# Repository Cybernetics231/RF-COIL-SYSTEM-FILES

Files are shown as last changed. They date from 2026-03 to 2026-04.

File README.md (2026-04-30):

# DB25 Control Software (Arduino + Avalonia UI)

This repository contains the full DB25 control software used to interface with an Arduino-based DB25 I/O system. It includes both the Avalonia-based graphical interface and the Arduino firmware that the GUI communicates with. The intent of this project is to allow anyone, even with no prior experience, to recreate the setup, understand how it works, and modify it if needed.

The graphical interface is built using Avalonia.NET to ensure compatibility with both Linux and Windows. The `.axaml` file defines the visual layout of the interface, while the `.axaml.cs` file contains the backend logic responsible for serial communication, pin updates, gain control, and pulse control. These two files together form the complete GUI.

For users who simply want to run the software, a ready-to-launch build is included in the `DB25 Mk3 Linux.rar` file. Extracting this archive provides the compiled `.exe` along with all required runtime files. This executable contains only the GUI portion of the project. The Arduino firmware must be uploaded separately and can be found in the `sketch_mar11a/sketch_mar11a.ino` directory.

If you intend to build on top of this software or compile the GUI yourself, the process is straightforward. Begin by installing the Avalonia UI .NET package and creating a new Avalonia project in Visual Studio. Once the project is created, replace the generated `.axaml` and `.axaml.cs` files with the versions from this repository titled `MainWindow.axaml` and `MainWindow.axaml.cs` by copying their contents directly into the corresponding files in your new project. After that, open a PowerShell terminal inside the project directory and compile the application using a publish command such as:

"dotnet publish -c Release -r win-x64 --self-contained true -o "$env:USERPROFILE\Downloads"" (Without end start and end quotations)

This will generate a standalone executable that can be run on Windows without requiring any additional installations.

The Arduino firmware used by the GUI is included in this repository and is located at `sketch_mar11a/sketch_mar11a.ino`. Upload this file to your Arduino using the Arduino IDE. Once the firmware is running, the GUI will automatically communicate with the board over serial, allowing you to read DB25 input pins, write output pins, adjust gain values, and control pulse output.

In addition to the software and firmware, this repository contains a folder titled **TEAM Files**, which includes the complete set of documents, calculations, and design artifacts produced during the capstone project. This folder is organized into several subdirectories. The `01-admin` folder contains all capstone-related documentation, including the final report and every presentation delivered to the sponsor, academic advisor, and other stakeholders. This is the best resource for understanding the full development process, design decisions, and project evolution.

The `02-RF amplifier` folder contains handwritten calculations, verification work, and a Python script used to compute the required input signal for the RF system. This is especially useful if the coil parameters change, as the script can be used to quickly recompute the necessary input waveform. The `03-TR switch` folder contains CAD files related to the transmit/receive switching hardware. The `05-Coil` folder includes coil parameters and VNA screenshots used during tuning and validation. Finally, the `Capstone fair` folder contains the poster and block diagram used during the public capstone showcase.

Some redundant files exist in the repository due to earlier development stages, but all essential components are present and functional. The goal is to provide a complete and transparent reference for anyone who wants to understand, use, or extend what was accomplished by the Capstone team of 2026 for the ULF RF System.

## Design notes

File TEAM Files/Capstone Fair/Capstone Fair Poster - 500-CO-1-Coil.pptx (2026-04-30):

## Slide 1

A Radio Frequency Coil for Ultra Low-Field MRI

Author(s): Jennifer Bee, Sonny Bruni, Yuri Lemermeyer, Kenshin Pacle, Spencer Tourigny, Ian Washington
Department of Electrical and Software Engineering at Schulich School of Engineering

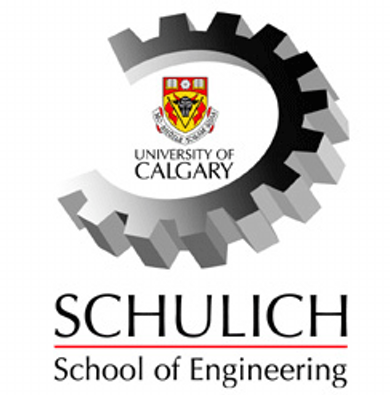
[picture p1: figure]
A new champion joins the 30 by 30 cause | Engineers Canada
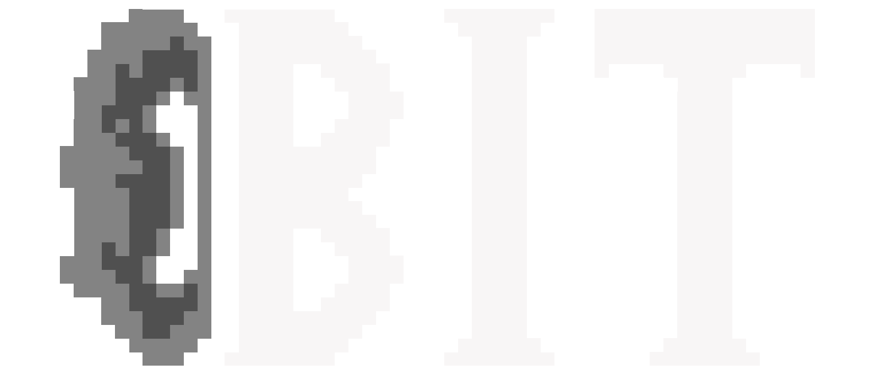
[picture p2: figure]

Introduction and Background

- Magnetic Resonance Imaging (MRI) is a key medical diagnostic tool. However, it is expensive because of the large magnetic fields it uses.

- Ultra-Low Field (ULF) MRI uses much lower magnetic fields, giving it the potential to make healthcare more affordable and accessible.
- Our project is the RF coil system of a ULF MRI. This system both excites the specimen and receives the signal it produces, which is processed into the image.

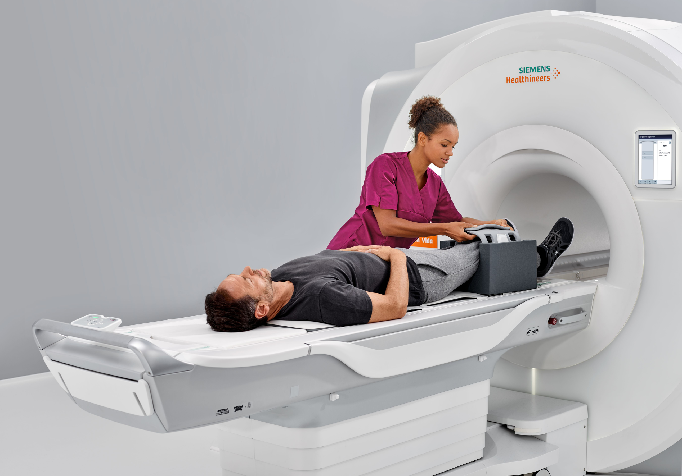
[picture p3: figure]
MRI Group – MRI Imaging Technology Includes Open MRI Machines

Tuning Circuit

- We manipulate the resonant frequency of the coil by adding capacitance in parallel.
- Series capacitance is added to maximize power transfer through impedance matching.

Simulations

- We simulated our coil’s resonant frequency and inductance to validate experimental results.

- Simulated resonant frequency: 4.221MHz
- Simulated inductance: 50μH

Results

- Achieved 2.18MHz tune with -43dB match
- Quality Factor (loaded with specimen): 175

Tuning of 2.18MHz ensures sample nuclei are properly excited.
Matched coil below -25dB indicates high efficiency power transfer.

Q Factor > 88 meets our goal for frequency selectivity because of its impact on signal to noise ratio.

- Experimental resonant frequency: 4.148MHz
- Experimental inductance: 54μH

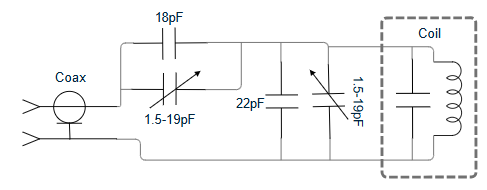
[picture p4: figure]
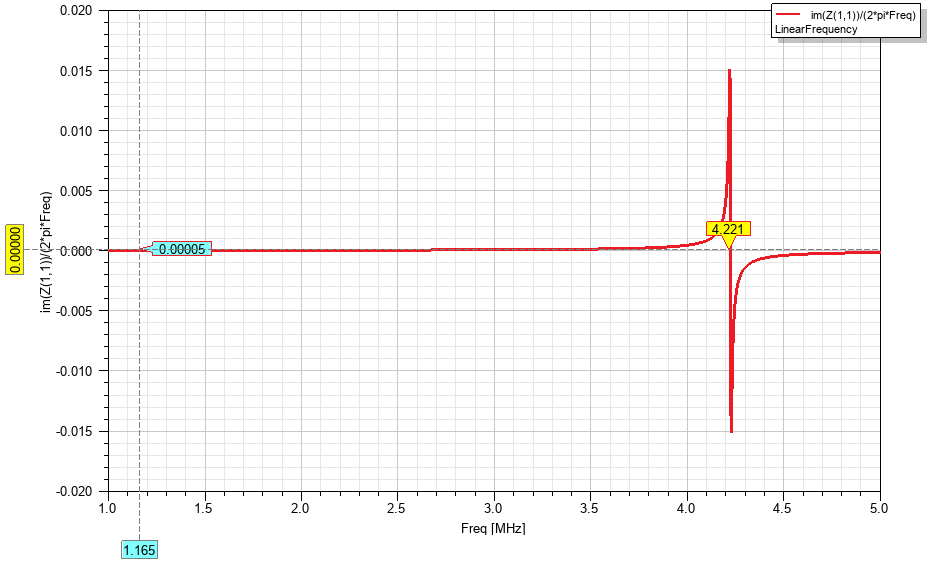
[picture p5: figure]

Radio Frequency Excitation

- RF Excitation is a phenomena where short bursts of radio waves at a specific frequency tilt the atoms of a magnetized sample away from a resting position.

- As the atoms decay back to their resting position, a distinct signal is produced which is used for imaging.

RF Amplifier

- The amplifier boosts a small signal, so the coil creates a strong enough field to tilt to the atoms. It is controlled via a 25-pin interface, by an Arduino and in-house GUI.

Transmit and Receive Switch

- The TR switch isolates the transmit and receive paths and quickly switches between them.

- Several factors including power handling and attenuation were considered for the selected design.

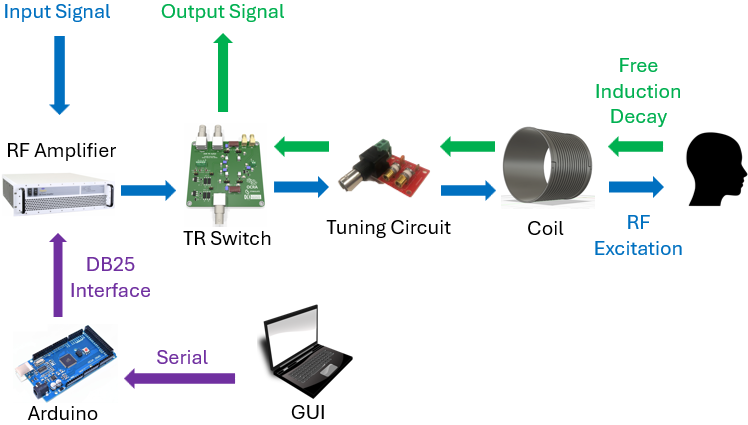
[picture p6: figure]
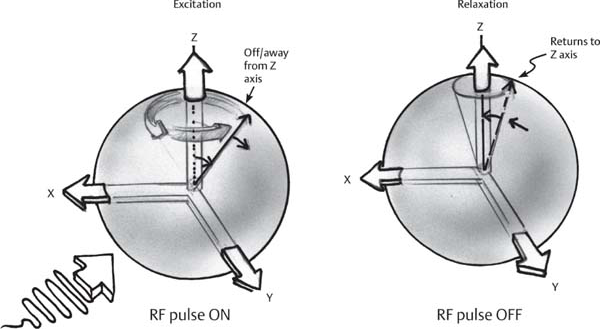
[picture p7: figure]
Essentials of MRI Physics and Pulse Sequences | Radiology Key

Coil Design

- Outer and inner diameters are 28.4cm and 26.4cm
- The coil has 15 turns, which sets the inductance

Geometric constraints permit measurement of adult heads and accommodate our sponsor’s existing ULF system.

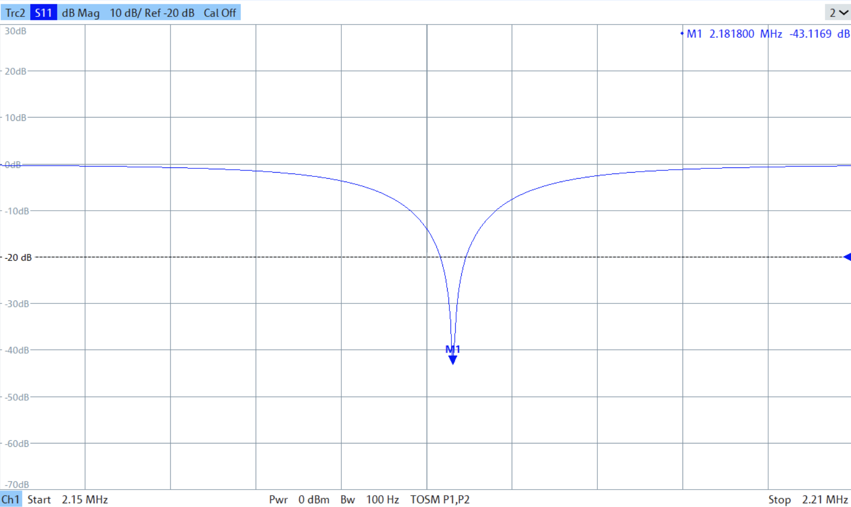
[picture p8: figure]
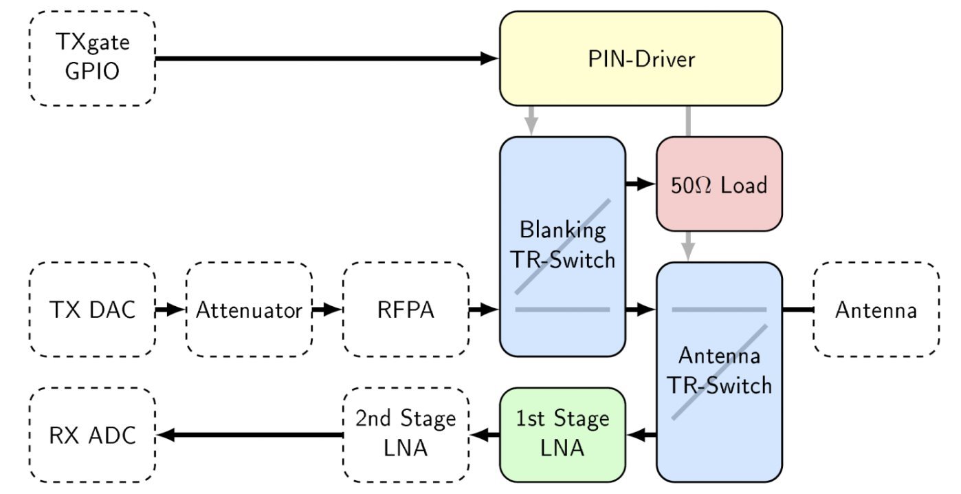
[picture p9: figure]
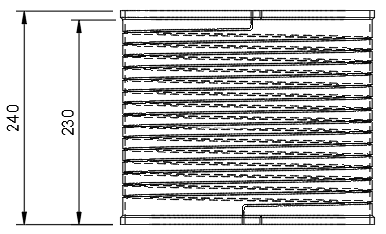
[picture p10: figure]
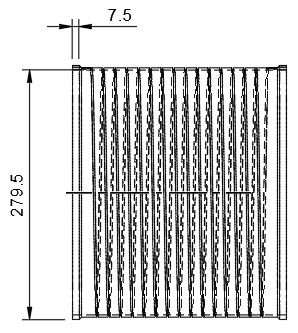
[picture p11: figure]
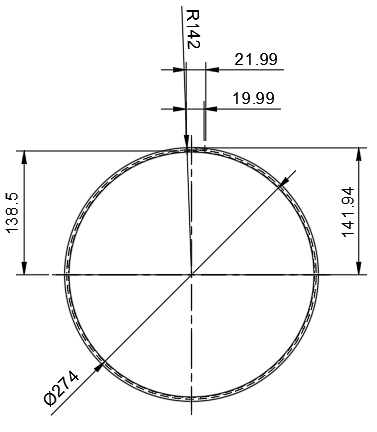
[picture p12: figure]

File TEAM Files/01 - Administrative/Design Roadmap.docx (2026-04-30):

A Radiofrequency Coil for Ultra Low-Field MRI

Design Roadmap

500-CO-1-Coil

Project Manager

Spencer Tourigny, 30117572, spencer.tourigny@ucalgary.ca

Team

Sonny Bruni, 30149849

Ian Washington, 30116633

Jennifer Bee, 30094595

Yuri Lemermeyer, 30143884

Kenshin Pacle, 30116862

Support Technician

Mateo Alzate

Academic Advisor

Dr. Chathura Kumaragamage

Company Sponsor

Brain Image Team (BIT) Lab

Dr. Ethan MacDonald, ethan.macdonald@ucalgary.ca

Table of Contents

# 1 Glossary

Acronyms | Definitions
RF | Radio Frequency
MRI | Magnetic Resonance Imaging
TR | Transmit-Receive
FID | Free Induction Decay
PCB | Printed Circuit Board
ULF | Ultra Low Frequency

Table 1: Definition of Acronyms Used Throughout the Document

Terms | Definitions
Larmor Frequency | Frequency of a charged particle’s magnetic moment in an external magnetic field
Free Induction Decay | Time-domain signal that appears immediately after a radio frequency pulse excites a sample’s nuclear spins.
Specimen | The object being imaged by the MRI

Table 2: Definition of Terms Used Throughout the Document

# 2 Short Bios

## 2.1 Spencer Tourigny

Final year Electrical Engineering and Commerce dual degree student. Industry experience in facilities engineering, electrical design, and maintenance engineering. Also completed a summer of undergraduate research in the University of Calgary control systems lab.

## 2.2 Jennifer Bee

Final year Electrical Engineering student with internship experience at the department of National Defence. Experience within RF detection systems and researched diode detection through RF excitation.

## 2.3 Ian Washington

Final year Electrical Engineering student with industry experience in fiber optic technology, data processing algorithms, and pipeline operations. Completed a digital engineering-focused fellowship opportunity at the University of Calgary.

## 2.4 Sonny Bruni

Final year Electrical Engineering student with industry experience in data analytics, manufacturing and engineering optimization.

## 2.5 Kenshin Pacle

Final year Electrical Engineering student with an industry background in software development and electrical systems. Interests in bridging software to hardware, and artificial intelligence.

## 2.6 Yuri Lemermeyer

Final year Electrical Engineering student with industry experience in power systems and data analytics.

# 3 Project Motivation and Objectives

## 3.1 Motivation

MRI is a diagnostic tool used to visualize the body’s internal structures. It is critical in diagnosing several ailments, including brain injuries, tumours, aneurysms, spinal cord conditions, and strokes (Mayo Clinic, 2023). However, conventional MRI machines rely on strong magnetic fields, which require expensive parts and complex fabrication. These factors make MRI technology inaccessible in many parts of the world, especially rural areas and third-world countries.

ULF MRI addresses this problem by offering an alternative approach. It uses weak magnetic fields, effectively reducing the size, cost and complexity of MRI systems. However, using a weak magnetic field creates new challenges, such as weak signals and blurry images, requiring thoughtful design to create a feasible solution. The RF coil, the part of a MRI which transmits and receives signals from the object being scanned, is especially impacted by the use of ULF, as the signal-to-noise ratio radically decreases in ULF applications.

## 3.2 Objectives

The main goal of this project is to design, build and test an RF coil optimized for ULF MRI applications. By completing this project, the team aims to contribute to the development of more affordable and accessible MRI technology. Ultimately, this project supports efforts to make healthcare more equitable and affordable through innovative engineering.

# 4 Project Scope and Deliverables

## 4.1 Project Scope

The scope of this project entails the design, fabrication, implementation, and validation of an RF coil to be used in the application of an ultra-low field MRI. The coil will serve as the primary driver for nuclear spin excitation in the specimen, as well as the reception of the free induction decay signal after radio signal pulsation at the Larmor frequency.

The final system shall include:

- An RF Coil.
- A tuning circuit that optimizes power transfer to the coil.
- A TR switch to control transmitting and receiving modes of the coil.
- An RF power amplifier to drive the Larmor frequency signal to the coil.

The coil, as well as the supplemental components shall be designed given the constant that the ultra-low field MRI produces a constant magnetic field of 50mT.

Functionality wise, the RF coil shall be capable of bimodal operation, utilizing both transmit and receive modes governed by the TR switch. In transmit mode, the coil shall be able to deliver an RF signal at the Larmor frequency corresponding to the defined magnetic field strength, driven by an RF amplifier, to induce excitation in the specimen. In receiving mode, the coil shall detect the FID signal resulting from free induction decay.

Constructing an image from the FID signal, main magnetic field generation for magnetizing the specimen, or any other functionalities that a completely functional ultra-low field MRI has is out of scope for this project.

## 4.2 Project Deliverables

Must-Have:

  - Functional RF Coil able to transmit and receive.
  - RF amplifier either designed or bought.
  - T/R Switch either designed or bought.
  - Tuning Circuit, tuning the coil for max power designed on a PCB.
  - Bill of materials.
  - Simulation results.
  - CAD Models for enclosures and Drawings.
  - 3D Printed enclosures for relevant components.
  - Documentation regarding design, as well as any supporting documentation or calculations.
  - Validation results, as well as metrics for performance of the system.

Should-Have:

- Modular PCB layout for Tuning circuit
- Solenoid coil design as opposed to traditional coil design.
- External circuit protection consisting of relays and fuses spread out through the components of the design.

Nice-to-Have

- Coil segmentation, Bandpass filters, decoupling capacitors, or any other noise mitigation implementations.
- Heat protection.
- Aesthetically pleasing enclosure.

# 5 Preliminary Design of the Proposed Solution

The RF coil system can be represented by the block diagram in Figure 1.

Figure 1: System Block Diagram

The basic function of the RF coil system is to take an input signal (supplied to the system, outside the scope of the project) and use it to generate a visualization of the specimen in the MRI. This visualization signal is outputted from the RF coil system to be processed (image processing is outside the scope of this project).

The RF coil performs this functionality by oscillating between two modes of operation: transmitting and receiving.

In transmission mode the system behaves as shown in Figure 2. The input signal is amplified by the RF amplifier and passes through the TR switch. The coil acts as a transmitting antenna, transmitting the signal into the specimen. This causes the spins of the hydrogen atoms in the specimen to align, creating a net magnetic moment in the specimen (Gould & Edmonds, 2023).

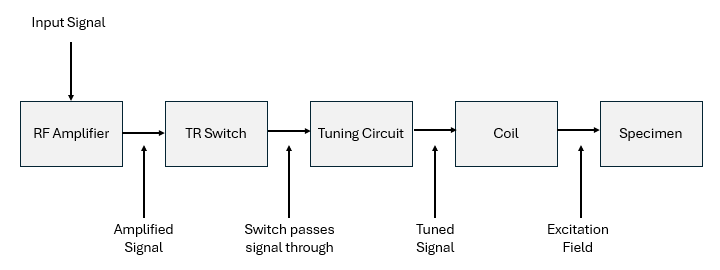
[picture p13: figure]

Figure 2: Transmission Mode Diagram

The system than switches to receiving mode. This causes the coil to stop acting as a transmitting antenna, ceasing the excitation of the specimen. However, the net magnetic moment in the specimen takes a while to decay (Gould & Edmonds, 2023). This gives us the chance to use the coil as a receiving antenna, picking up the FID signal generated by the specimen. This signal is passed through the RF coil system as shown in Figure 3, eventually being outputted and used to produce the visualization of the specimen.

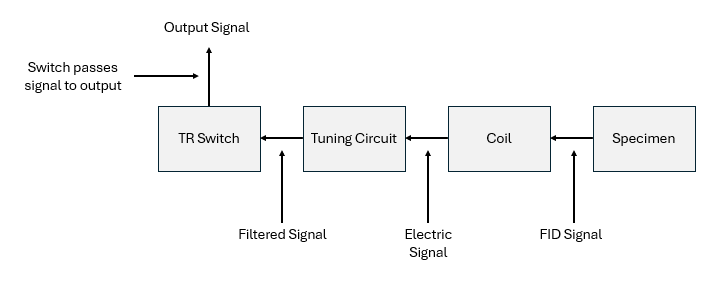
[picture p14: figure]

Figure 3: Receiving Mode Diagram

These block diagrams show the project design can be broken into 4 main components: the coil, the TR switch, the RF amplifier, and the tuning circuit.

## 5.1 Coil

The coil is made up of an antenna and housing. The size of the coil and coil housing is very important because it must fit the specimen inside it, while being able to fit inside the larger permanent and gradient magnets itself. Sizing requirements are given in the technical requirements. To reliably meet these sizing requirements, and simplify construction of the housing, the housing will be 3D printed.

The antenna itself can have several design alternatives, though most involve wrapping magnet wire around the housing in some configuration. These configurations will be discussed in the alternative solutions section below. The use of magnet wire is important for the antenna to effectively transmit a signal to the specimen.

## 5.2 TR Switch

There are several TR switch designs which have been used in MRI systems over the years, including both active and passive switching options. To avoid repetition, I will save the discussion of these alternative switches and our planned path forward for the alternative solutions section of this report.

## 5.3 RF Amplifier

Our sponsor purchased an RF amplifier prior to the beginning of our project with them. This purchased RF amplifier is a Tomco brand 3MHz RF amplifier. Our design should be compatible with this amplifier.

## 5.4 Tuning Circuit

Our tuning circuit will be based off the design done by Tom O’ Reilly and Lukas Winter, who developed a tuning circuit for a similar ULF MRI application (O’ Reilly & Winter, 2025). A schematic of O’Reilly and Winter’s tuning circuit design is given in Figure 4.

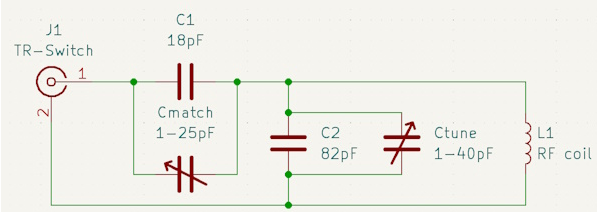
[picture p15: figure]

Figure 4: O’Reilly and Winter's Tuning Circuit Schematic

However, our design will have to make a few changes to this design. First, the variable capacitors they used are not readily available in North America. Instead, we will use alternative variable capacitors in our designs. These capacitors have different capacitance ranges than the ones used by O’ Reilly and Winter. To get an equivalent circuit with different capacitance ranges, we will need different capacitance and inductance values for static components. To test that our redesigned circuit still functions correctly, we will prototype it on a breadboard, to test its functionality. After we have confirmed the functionality of our tuning circuit, we will print a tuning circuit PCB, to eliminate any stray breadboard capacitances from the final design.

# 6 Alternative Solutions and Methodologies

## 6.1 General Approach to Design Alternatives

Since low-field MRI devices are a new technology with limited pre-set industry standards, and limited literature and research papers available, there have been cases where the team and/or sponsor have chosen to use off-the-shelf, pre-built components for initial testing and validation. This way, troubleshooting is much more straightforward and there is a working example with which to base further designs off.

The downsides of using this approach are that in some cases using pre-built components is more expensive than designing a solution ourselves, and that pre-built components are more difficult/impossible to modify if needed.

## 6.2 Simulation Software Alternatives

Simulation software was chosen based on familiarity, technical capabilities, and cost. The three main options considered were Python, MATLAB and Ansys Electronics Desktop. MATLAB was familiar to the team but not specifically for electromagnetic and radio-frequency modelling and is limited to relatively rudimentary geometric modelling. For our use case, Python has mostly the same benefits and drawbacks as MATLAB. Experience with Ansys was limited to a few labs in previous classes, however it has superior ability to model geometry, and simulate radio frequency responses. MATLAB and Ansys provide university students access to a free version. In Ansys Electronics Desktop Student the user is limited to 10,000 meshes which has limited, but not detrimentally so our simulations. We chose Ansys as a more specialized and powerful tool for MRI modelling.

## 6.3 RF Coil Design Alternatives

For the design of the main RF coil, we considered three configurations: birdcage, solenoid (helix), and surface coils. Factors considered included the specialization of the coil, such as depth of imaging and quality of signal to noise ratio. We also took into account coil design, simulation and manufacturing complexity. Lastly, we considered availability of open-source information about design and performance as a favourable source of guidance. Surface coils would have been a strong choice in a different context of imaging. If our focus was limited to shallow images (such as wrists, elbows, knees, etc.) we would have considered these coils further. However, these designs are very complex and the amount of open-source information available regarding these coils is not plentiful. Between the remaining two choices of coils, birdcage have better field homogeneity. While this is an important parameter, it was outweighed in favour of the solenoid design’s superior signal to noise ratio, significantly simpler design and plentiful access to open-source resources. We heavily referenced open-source resources provided by Lukas Winter, and our initial design closely follows his Solenoid d205mm N20 3seg design (O’Reilly & Winter, 2023).

## 6.4 TR Switch Design Alternatives

The TR switch is one of the most open-ended parts of the overall design, with many possible solutions according to cost, space, switching time, isolation, and power handling constraints. Preliminary research into TR switches used by other teams attempting to build similar MRI machines yielded two potential open-source options: a passive TR switch with limited design specs and material list, and an active TR switch PCB with a complete bill of materials and PCB design files.

Further research was done into using an off-the-shelf radio-frequency switch instead of the open-source options. A paper published by a team building and testing a similar low-frequency MRI device compared 4 different TR switch designs using switches available for purchase online (Sappo et al., 2020).

Table 3 was included in the paper and compares four metrics that are important for determining the efficacy of the TR device. The passive switch here is similar to the other passive switch used by other teams. Based on these results, along with the price of each TR switch, we decided to use the ADG1412 digital switch for initial testing. This switch has the best switching speed and isolation, good power handling and insertion loss, and is relatively cheap.

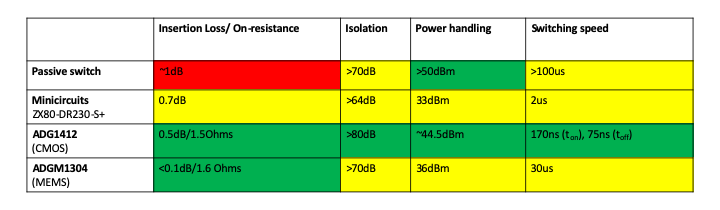
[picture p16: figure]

Table 3: Comparison of TR Switch Alternatives

## 6.5 Power Amplifier Design Alternatives

Other groups designing low-field, low-cost MRI devices have often built their own power amplifiers for their design. However, for our project, our sponsor chose to buy a power amplifier for the first stage of development. If time and resources permit, developing our own power amplifier could be possible.

# 7 IP and Other Legal Agreements

This project is governed by the sponsor-team contract. Both the sponsor and the team have copies of this contract, and it has also been submitted on D2L. This contract gives possession of the project results, including any IP to the sponsor.

# 8 Technical Specifications

Specification | Requirement
Coil type | RF solenoid
Coil turns | 20
Coil length | 20cm
Coil diameter | 20.5cm
Wire length | ~12.9m
Weight (solenoid and tuning circuitry) | <8lbs
Coil body material | PLA
Reflection coefficient magnitude at tuned frequency | |S11| < -12dB
Budget | $1900

Table 4: Project Technical Specifications

# 9 Materials, Supplies, Tools, and Cost Estimates

Materials | Cost Estimate | Purpose
3D-printed chassis | $0 | Main body for RF coil
Magnetic wire | $300 | Wire for winding coil
Variable capacitors (x2) | $700 | Tuning Circuit
Ceramic capacitors | $0 | Tuning Circuit
Tuning Circuit PCB | $100 | Tuning Circuit
Breadboard | $0 | Tuning Circuit (testing)
TR Switch | $400 | TR Switch
Amplifier | $300 | Amplifier
Simulation Tools | $100 | Simulation and Design Testing

Table 5: Project Materials and Supplies with Cost Estimates

Equipment | Purpose | Access
Network Analyzer | Testing | Sponsor's lab
Oscilloscope | Testing | Sponsor's lab
3-D Printers | Printing 3D chassis | Sponsor's lab
Soldering station | PCB assembly | Electrical makerspace
Ansys software | Simulations | Free software
Signal generator | Generate RF signal | Sponsor’s lab

Table 6: Project Tools and Lab Equipment

The overall project budget is $1900 +/- 10%.

# 10 Risks and Risk Mitigation Plans

Deliverables | Risks | Mitigation Plans
RF Coil | 1) Copper wire does not arrive within appropriate time. 2) Solid copper wire is not effective for receiving. | 1) Monitor delivery progress and make another local order if needed. 2) Make simultaneous order for stranded copper wire.
RF Amplifier | 1) Internal circuit protection does not work, and the RF amplifier gets burned out. 2)RF amplifier does not meet the requirements. | 1)Create external circuit protection for the system, ensuring either relays or fuses burn before amplifier is harmed. 2)Switch out RF amplifier or add external circuit supplementing RF amplifier.
T/R Switch | 1) TR device gets burned out or otherwise damaged during testing/operation 2) TR switch does not meet switching time requirements needed to effectively receive signal back from the sample | 1) For devices with limited built-in power protection, extra units may be acquired in case one gets damaged. 2) Do appropriate research and simulations to ensure that the switching time will work
Tuning Circuit | 1) Components purchased for the tuning circuit meets the requirement of the reference coil, but not the requirements of the bird cage design. 2)Tuning circuit gets burned. | 1.1) Design the PCB to be modular, or similar to a capacitor bank allowing the addition of components. 1.2) Breadboard the design first, then order the PCB. 2)Add external circuit protection.
Simulation | 1) Sponsor takes too long to find professor that can provide full Ansys access | 1.1) Request purchase of Ansys license during next meeting with sponsor 1.2) Make simulation using MATLAB or Python if Ansys license purchase is not an option
Testing and Validation | 1) Network Analyzer delivery is further postponed or cancelled | 1) Ask sponsor during next meeting to look into Network Analyzer options on campus

Table 7: Project Risks and Risk Mitigation Plans

# 11 Major Technical Tasks and Milestones

Phase | Milestone | Tasks
Phase 1: Research & Component Acquisition. | Gaining technical aptitude and completing procurement of materials. Timeline: Start of Project – Fall Term Progress Evaluation | - Study what an ULF MRI is. - Study RF principles. - Definition of team roles. - Identify components needed for the system. - Identify input signal characteristics such as amplitude and frequency. - Preliminary coil simulations. - Base schematics of the tuning circuit. - Acquisition of materials needed for phase 2. - Finalize design characteristics such as coil size, etc.
Phase 2: Prototype System, | Prototype coil system to be assembled and tested to be used for baseline metrics. Timeline: Fall Term Progress Evaluation – Start of Winter Semester | - Prototype design based on documentation. - Implement all components of the system discussed in Phase 1. - Perform and document validation tests for performance and benchmarking. - Requisition additional parts as needed.
Phase 3: Solenoid Coil Design and Fabrication. | Fabrication of the solenoid coil to improve system performance Timeline: Start of Winter Semester – Winter Term Progress Evaluation | - Simulation of solenoid coil. - Design solenoid coil. - Construct solenoid coil. - Requisition additional parts as needed.
Phase 4: Solenoid Coil Tuning. | Tuning circuit matched to the coil. Timeline: Winter Term Progress Evaluation – Mid-February 2026 | - Create a tuning circuit for the solenoid coil. - Requisition additional parts as needed.
Phase 5: Final Validation tests. | Final testing of the solenoid coil . Timeline: Mid-February 2026 – Final Presentation | - Perform and document final validation tests to compare to the original design. - Requisition additional parts as needed.

Table 8: Project Phases and Milestones

The Major technical tasks and milestones have been split into phases that reflect a hybrid agile development process.

Phase 1 is the preliminary stage of the design. Essentially FEED. It lays the foundation for the group to understand what exactly an ultra-low field MRI is, and how the system being developed fits into the puzzle. This is also time to requisition parts that will be needed for phase 2 and further phases.

Phase 2 puts everything established in phase 1 into motion. A physical product is produced that will serve as the baseline that will be improved upon in further phases.

Phase 3 is the design and fabrication of a solenoid coil intended to surpass the baseline system in efficiency and quality of FID signal received. Efforts are to be focused on optimizing coil geometry and material selection to improve RF performance.

Phase 4 is integrating a custom-tuned circuit to ensure impedance matching and resonance at the target frequency. PCB adjustments or re-iteration from baseline are made as necessary to accommodate new coil parameters.

Phase 5 is comprehensive testing conducted to evaluate the performance of the solenoid coil against the baseline. This is also closeout.

Note that the phases set up are meant to mimic the project life cycle gating control standards used within industry.

# 12 Roles and Responsibilities

Member | Role
Spencer | Project Manager: - Ultimately responsible for all course deliverables - Responsible for coordinating meetings with the sponsor, TA, and academic advisor, as well as internal meetings - Responsible for assigning and enforcing internal deadlines - Responsible for overall system architecture and ensuring the designs of each sub team are compatible - Also accountable for assisting coil and TR switch leads on technical duties, as required
Jennifer | Coil Lead: - Responsible for the design and 3D printing of the coil - Responsible for the construction of the coil - Responsible for the testing and validation of coil parameters (impedance value, S11 parameter, etc.) - Responsible for coil documentation - Also accountable for assisting simulation lead on technical duties, as required
Ian | TR Switch Lead: - Responsible for the research of alternative TR switches - Responsible for the testing of alternative TR switches and evaluation of their technical capabilities - Responsible for the selection of the final TR switch from the alternatives - Responsible for TR switch documentation
Sonny | Simulation Lead: - Responsible for the simulation of the coil design, and determining theoretical parameters - Must consult with coil lead to ensure the simulated design matches the real coil - Responsible for simulated alternative designs - Responsible for documenting simulation results
Ken | Tuning Circuit Lead: - Responsible for the design of the tuning circuit - Responsible for the prototyping of the tuning circuit - Responsible for the validation of the tuning circuit design - Responsible for investigating alternative amplifier designs and implementations - Also accountable for assisting tuning circuit PCB lead on technical duties, as required
Yuri | Tuning Circuit PCB Lead: - Responsible for the design of the tuning circuit PCB - Responsible for the testing and validation of the PCB - Also accountable for assisting tuning circuit lead on technical duties, as required

Table 9: Project Roles and Responsibilities

# 13 Measures of Success and Validation Tests

Signal Quality Testing

- Using the network analyser, we will find the of the tuning circuit. To be successful, the resonance frequency should be close to the middle of the chart, implying good or near perfect tuning (e.g. minimal VSWR).

System Stability Testing

- There should be no thermal drift in the system. The coil and electronics should be able to remain stable and working over long periods of operating time. To test this, we will measure the frequency drift due to temperature changes as the coil operates. To be successful this drift should be insignificant.

Coil Parameters

- Using the network analyser, we will measure the S11 reflection coefficient of the coil. To be successful the magnitude of the measured value at the tuned frequency should be less than -12dB.

Coil Geometry

- Using a measuring tape and scale, we will measure the geometry and weight of the coil and coil housing. If these values meet the technical specifications, this test will be considered successful.

# 14 Team Logbook

A logbook will be created using Planner in Microsoft Teams and will include sections such as Backlog, Up Next, In Progress and Completed. Anyone in the team may add a new task within these sections. These tasks will be updated to indicate progress, and any important updates regarding the task which were shared during team meetings. Team members will be responsible for updating the logbook ensuing all work on the project, and discussions during team meetings, are logged. Team members must also update the sections in which their tasks reside. For instance, a task that is no longer in progress must be updated as complete. This will ensure effective organization and logbook maintenance. Lastly, the project manager will be responsible for reviewing the logbook during each internal meeting and ensuring consistent and appropriate use.

# 15 References

Gould, T. A., & Edmonds, M. (2023, June 9). How MRI works. How Stuff Works. https://science.howstuffworks.com/mri.htm

Mayo Clinic. (2023, September 9). What is an MRI scan used to diagnose? https://www.emedicinehealth.com/what_is_an_mri_scan_used_to_diagnose/article_em.htm

O’Reilly, T., & Winter, L., (2023, January 6). Solenoid d205mm N20 3seg. Gitlab. https://gitlab.com/osii/rf-system/rf-coils/solenoid-d205mm-n20-3seg

O’Reilly, T., & Winter, L., (2025, May 14). Solenoid d150 N20. Gitlab. https://gitlab.com/osii/rf-system/rf-coils/solenoid-d150-n20

Sappo, C.R., Martin, M. N., Shen, S., Koonjoo, N., Kos, A. B., Grissom, W. A., Rosen, M. S., & Stupic, K. F. (2020). Active transmit/receive switches for low field magnetic resonance (<100mT). International Society for Magnetic Resonance in Medicine. https://cds.ismrm.org/protected/20MProceedings/PDFfiles/4067.html#:~:text=A%20TR%20(transmit%2Freceive),effective%20switches%20and%20widely%20used.

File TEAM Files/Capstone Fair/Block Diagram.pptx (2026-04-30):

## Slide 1

Input Signal

Output Signal

RF Amplifier

TR Switch

Tuning Circuit

Coil

Specimen

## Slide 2

Input Signal

RF Amplifier

TR Switch

Tuning Circuit

Coil

Specimen

Amplified Signal

Switch passes signal through

Tuned Signal

Excitation Field

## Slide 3

Output Signal to ADC

RF Pre-Amplifier

TR Switch

Tuning Circuit

Coil

Specimen

Switch passes signal to output

Filtered Signal

Electric Signal

FID Signal

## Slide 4

Input Signal

Output Signal

Free Induction Decay

RF Amplifier

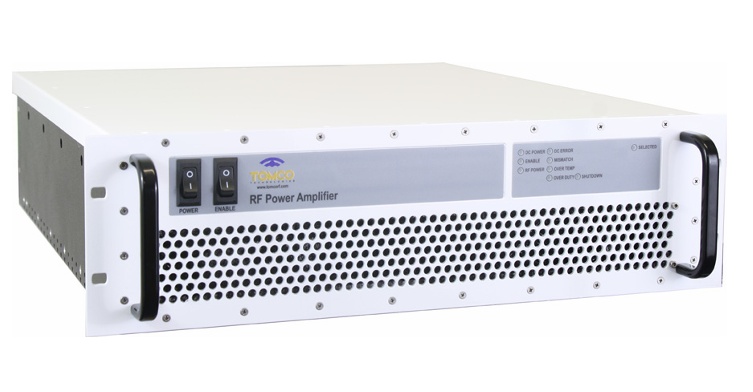
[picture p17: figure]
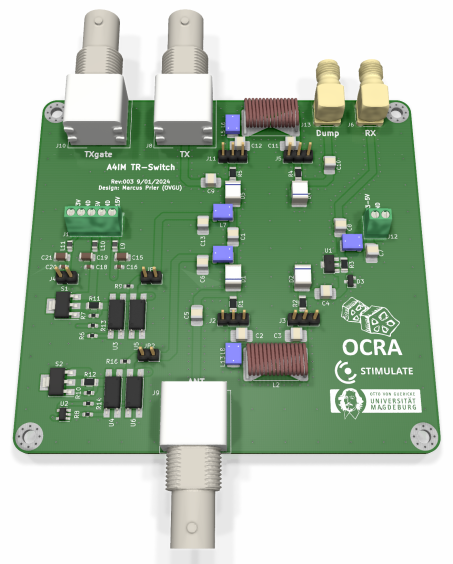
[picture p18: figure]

TR Switch

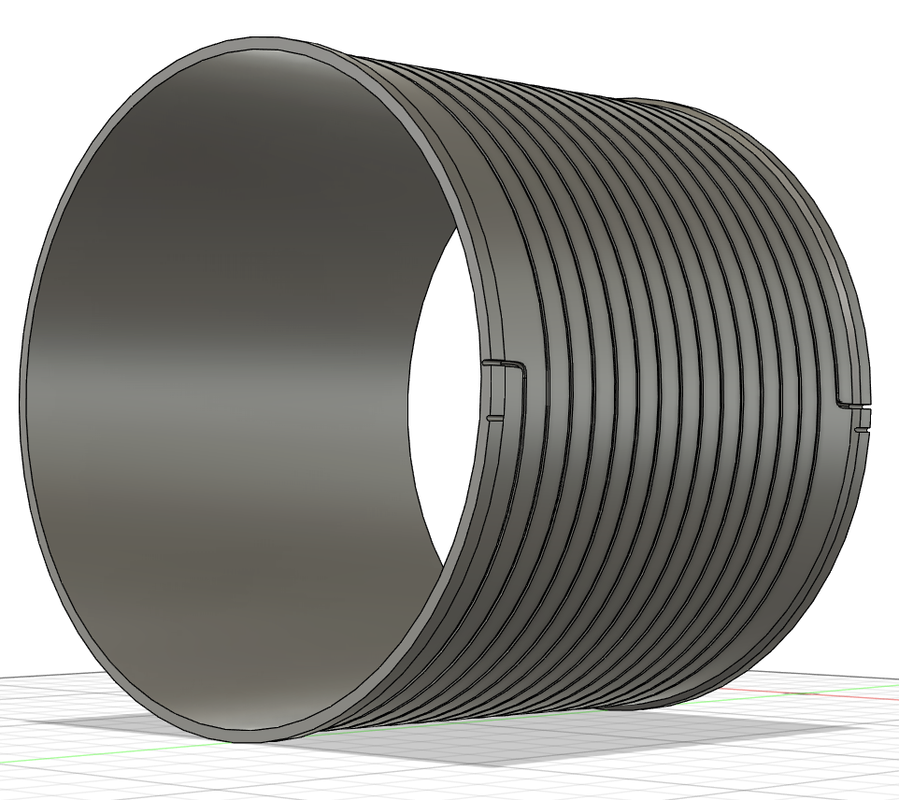
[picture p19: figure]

Coil

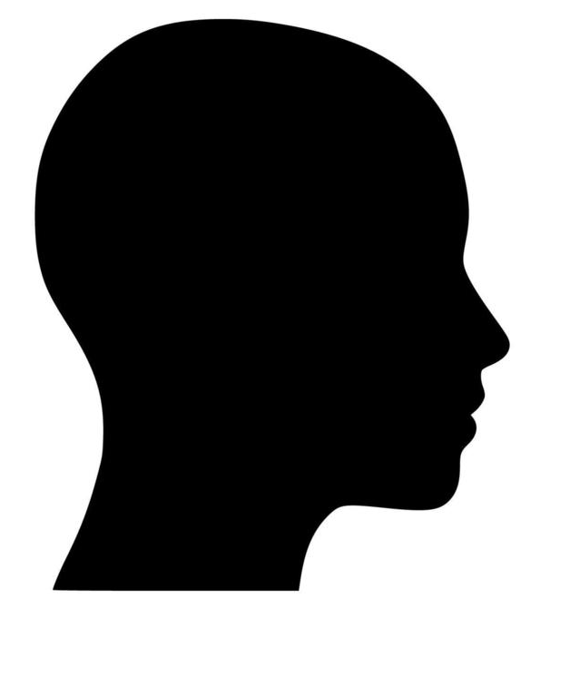
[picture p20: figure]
Human Head Silhouette Vector Art, Icons, and Graphics for Free Download
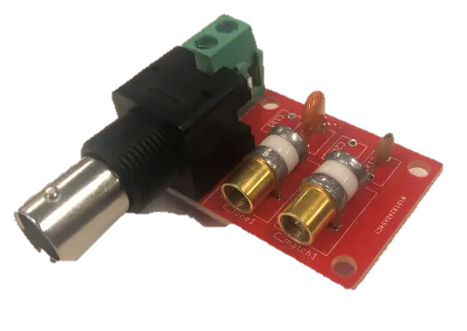
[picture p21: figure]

Tuning Circuit

RF Excitation

DB25 Interface

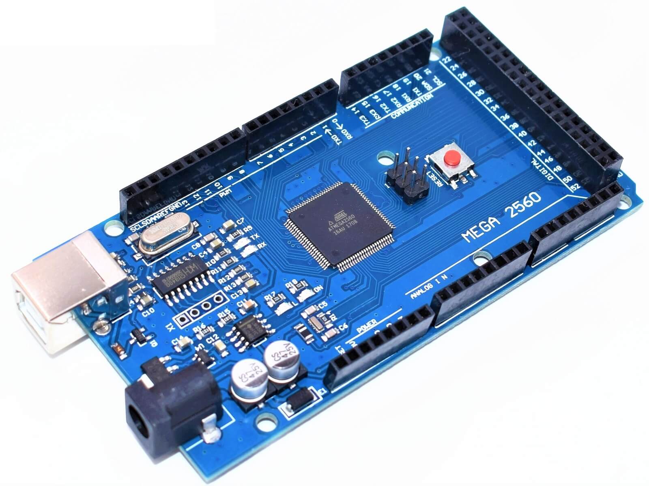
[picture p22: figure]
Arduino Mega 2560 Rev3 — Характеристики, распиновка, описание - DIY и Электроника

Arduino

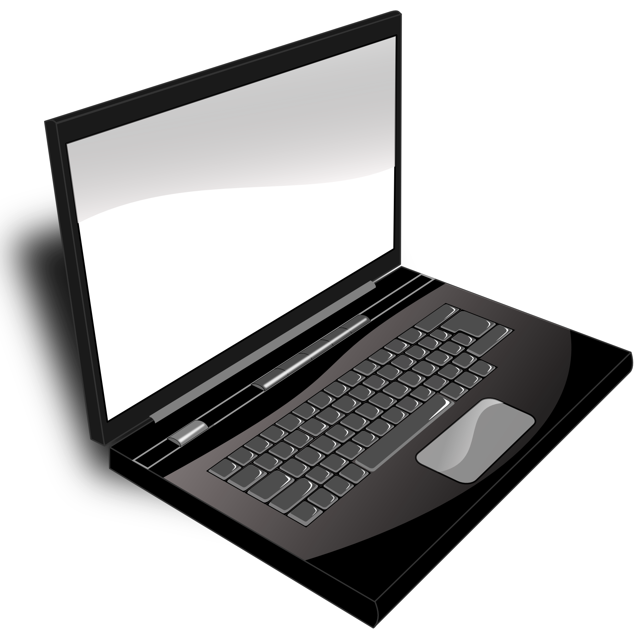
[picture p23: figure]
Free Laptop Clipart Transparent, Download Free Laptop Clipart Transparent png images, Free ...

GUI

Serial

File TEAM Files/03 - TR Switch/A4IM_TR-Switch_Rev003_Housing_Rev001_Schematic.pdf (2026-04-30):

Part | Manufacturer / Datasheet | Part # | Supplier | Order # | URL | QTY | Costs | Total Cost
Hammond Case | https://www.mouser.de/datasheet/2/177/1455-1272397.pdf | 1457N1201EBK | Mouser | 546-1455N1601BK | https://www.mouser.de/ProductDetail/Hammond-Manufacturing/1457N1201EBK?qs=ptj1V1atRAogHmwtUWthwg %3D%3D | 1 | 50,310 € | 50,31 €
Hammond Case Flanged | https://www.mouser.de/datasheet/2/177/1455-1272397.pdf | 1457N1202EBK | Mouser | 546-1457N1202EBK | https://www.mouser.de/ProductDetail/Hammond-Manufacturing/1457N1202EBK?qs=ptj1V1atRAqX6ia%2F9733NQ %3D%3D | 1 | 51,490 € | 51,49 €
DC-Connector Hi-Temp 2.5mm | Switchkraft | 712AH | Mouser | 502-712AH | https://www.mouser.de/ProductDetail/Switchcraft/712AH?qs=%2Fha2pyFaduhTlifiILeZms9XMzn gvbmjLPbfHmF6Lso1xMYcLcGJK w%3D%3D | 3 | 4,020 € | 12,06 €
Capacitor 10nF 5% 50V Radial | KEMET | C320C103J5G5TA917073 01 | Mouser | 80-C320C103J5G9170-R | https://www.mouser.de/ProductDetail/80-C320C103J5G9170-R | 3 | 0,733 € | 2,20 €
BNC Nut | TE Connectivity | 1-329631-2 | Mouser | 571-13296312 | https://www.mouser.de/ProductDetail/TE-Connectivity-AMP/1-329631-2?qs=Mv1qlCsH0%252BFYft3mR eny%2FQ%3D%3D | 3 | 0,390 € | 1,17 €
Cable | Lapp H05V-K 0.5mm² BK WH | | Farnell | | https://de.farnell.com/lapp-kabel/4510011/litze-h05v-k-0-5mm2-schwarz-100m/dp/1204068 | 1m | 1,000 € | 10,00 €
| | | | | | | ∑ | 127,23 €

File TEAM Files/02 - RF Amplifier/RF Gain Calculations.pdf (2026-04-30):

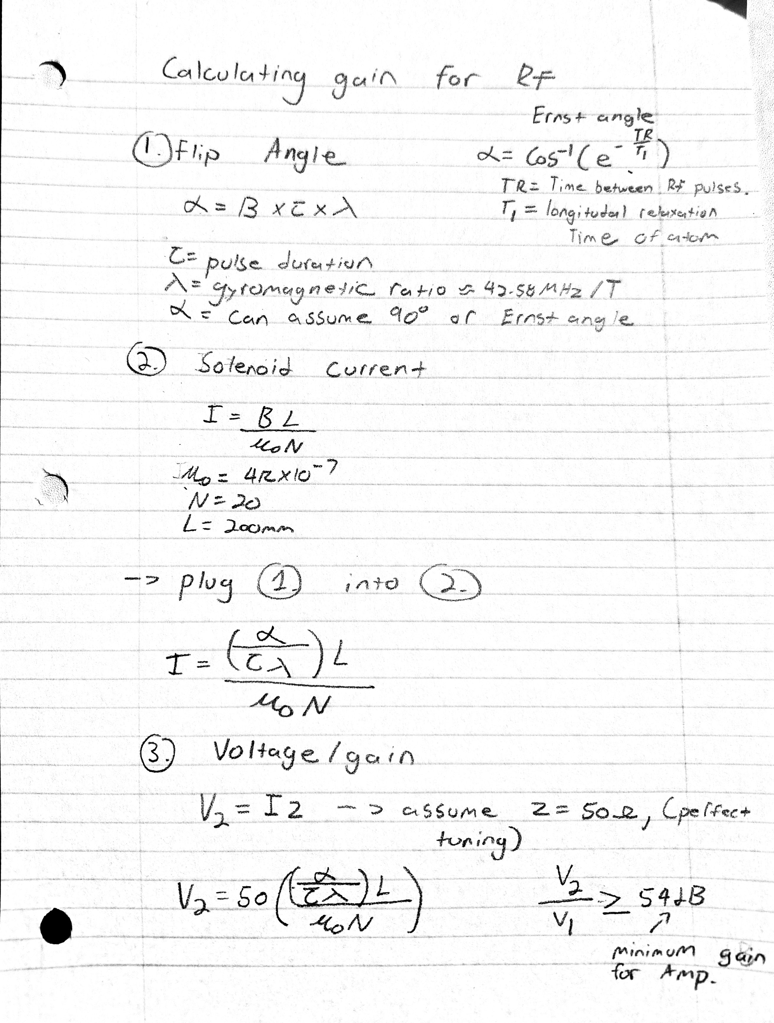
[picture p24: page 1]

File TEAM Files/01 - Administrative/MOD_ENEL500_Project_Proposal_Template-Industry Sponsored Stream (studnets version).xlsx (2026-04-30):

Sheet: Project Inforrmation
ENEL 500- Project Description Template
Industry-Sponsored Projects
Project Information
Note1: please do not modify any of the titles etc. Only fill in the required information.
Note2: please submit one file per team through D2L.
Note 3: please complete all three sheets in this file.
Interim Project Manager (The student who will be submitting the proposal on behalf of the team) | One of the team members who has accepted to be responsible for managing the team at this initial stage needs to be introduced. | The interim project manager will submit the proposal.
Last Name | Tourigny
First Name | Spencer
Student Number | 30117572
Email | spencer.tourigny@ucalgary.ca
The Project
Project Title | A Radiofrequency Coil for Ultra Low-Field MRI | Example: Development of a software solution for very short-term wind power forecasting
Project Motivation ("the problem") | Magnetic Resonance Imaging (MRI) is a crucial diagnostic tool widely used to visualize internal anatomical structures and assess physiological functions in clinical settings. Traditional MRI operates at high magnetic fields, requiring expensive equipment and infrastructure, making it less accessible globally, especially in resource-constrained or rural healthcare settings. Ultra Low-Field (ULF) MRI offers a promising alternative, leveraging lower magnetic fields that significantly reduce the cost, size, and complexity of MRI systems. However, current limitations include reduced signal-to-noise ratios and imaging resolution. The next phase in our construction of a low-field MRI system is the radiofrequency (RF) coil for excitation and data acquisition. This project aims to develop a specialized RF coil optimized for ULF MRI applications. Students will design, simulate, and construct an RF coil specifically tailored to operate efficiently at ultra-low magnetic fields. The coil should be carefully designed, rigorously tested and validated using computational simulations and bench testing, with the potential for integration into existing ULF MRI systems. The expected impact of this project is substantial. Successful development and optimization of this RF coil could significantly enhance image quality for the ULF MRI, making this affordable imaging technology more viable for widespread clinical use. Ultimately, this innovation can facilitate more equitable healthcare delivery b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 | Example: Our company has a tool for predicting wind power production in Alberta's power system. While the existing solution is sufficient for hourly long-term (up to a week into the future), it lacks certain features. In particular, it is not built to produce higher resolution forecasts (10-minute intervals) for very short-term (next 3 hours).Such very short-term forecasts are, however, necessary in our operation scheduling process. The objective of this project is build a tool to generate such forecasts. Please provide as much information about the problem and its motivation as possible at this stage.
Expected Outcome ("the solution") | The primary outcome of this project will be a fully functional and validated RF coil prototype optimized for ULF MRI. Deliverables include comprehensive coil design documentation, simulation results demonstrating performance, and experimental validation data confirming enhanced sensitivity and imaging quality.
Deliverable 1 | Design
Deliverable 2 | Protocol
Deliverable 3 | Validating Testing
Deliverable 4
add more if needed
Applicable Technical Areas
Primary Focus (mandatory) | Electronics
Secondary Focus (optional) | Biomedical
Tertiary Focus (optional) | Controls/instrumentation
 |  |  | Be specific; write it for a non-expert person in the field to understand; define all abbreviations;
 |  |  | Be specific; write it for a non-expert person in the field to understand; define all abbreviations;
 |  |  | List all the deliverables; I have listed four as an example here.

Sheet: Team Information
Team Members Information
Teams can have between 4 to 6 members. One more member ma be allowed in exceptionally large project where enough work can be justified for all members- such projects need special approval from the instructor, before end of August.
If a project is purely to develop a software, majority of he team members must be from the software program.
Please note that when deciding the number of team members, you should consider technical works, meetings, reporting etc. The expected time requirement per student is 250 hours over 8 months, and each team must have at least four team members.
 | Member #1 | Member #2 | Member #3 | Member #4 | Member #5 | Member #6
Last Name | Tourigny | Bruni | Washington | Bee | Lemermeyer | Pacle
First Name | Spencer | Sonny | Ian | Jennifer | Yuri | Kenshin
Student Number | 30117572 | 30149849 | 30116633 | 30094595 | 30143884 | 30116862
Email | spencer.tourigny@ucalgary.ca | Sonny.Bruni@ucalgary.ca | ian.washington@ucalgary.ca | jennifer.bee@ucalgary.ca | yuri.lemermeyer@ucalgary.ca | Kenshin.pacle@ucalgary.ca
Program | Electrical | Electrical | Electrical | Electrical | Electrical | Electrical
Team Name
Proposed Team name | MRInnovators

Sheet: Sponsor Information
Industry Sponsor's Information
 |  |  |  |  |  |  | This field should be "PEng",or "EIT".
 | Sponsor Company Name | Sponsor Company area of activity | Sponsor Company website | Sponsor's Representative Last Name | Sponsor's Representative First Name | Sponsor's Representative Email | Sponsor's Representative APEGA Status | Sponsor's Representative Job Title | Is the sponsor Providing Financial Support? (Yes/No)
 | Brain Image Team (BIT) Lab | Biomedical | https://www.brainimageteam.com/team.html | MacDonald | Ethan | ethan.macdonald@ucalgary.ca | PEng | Assistant Professor | Yes

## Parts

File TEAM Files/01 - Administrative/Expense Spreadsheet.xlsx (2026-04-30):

Item | Quantity | Price
Magnet Wire | 1 | $209.97
TR Switch | 3 | $16.33
Variable Capacitors | 2 | $137.49
BNC Connectors | 8 | $10.28
N to BNC Interconnects | 8 | $10.80
BNC Barrel Connects | 10 | $10.45
BNC Coax Cables | 10 | $22.34
DB25 Connector Adapter | 1 | $25.28
Arduino Mega | 1 | $27.95
Cable Sleeve | 1 | $13.99
Breakout Module for Arduino Mega | 1 | $49.83
Semi Rigid Coax | 2 | $66.61
Semi Rigid Coax | 2 | $59.12
Terminator | 1 | $668.12
Bidirectional Coupler | 1 | $225.48
BNC to SMA Interconnects | 8 | $7.59
BNC to SMA Interconnects | 4 | $12.83
N to BNC Interconnects | 2 | $11.29
TR Switch | 1 | $1700.00
Tuning Circuit PCB | 1 | $20.00
Field Components Order | 1 | $239.12
 | Total | $4386.33

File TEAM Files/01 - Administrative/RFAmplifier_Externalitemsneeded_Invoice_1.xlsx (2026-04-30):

Name | Reason | Price | Link | Needed Now
Grounding Cable | Ground needed for the RF amplifier. This grounding cable plugs directly into a wall and uses the ground of the outlet. | 19.99 | Link (https://www.amazon.ca/KarlKers-Shielded-Grounding-Alligator-Extension/dp/B0F9XC8B9W?s=hi) | Yes
Solid Wires | To connect each pin to the DB25 Connector Adapter | 22.99 or Free from makerspace | Link (https://www.amazon.ca/TUOFENG-Hookup-Wires-6-Different-Colored/dp/B0CM2Y7V1Z?sp_csd=d2lkZ2V0TmFtZT1zcF9hdGY) | Yes
DB25 Connector Adapter | The RF amplifier requires a DB25 cable to control it's settings such as gain, duty cycle, etc. | 25.28 | Link (https://www.amazon.ca/CERRXIAN-Connector-Terminal-Breakout-Plastic/dp/B07JNFMVB6) | Yes
Arduino Mega | Needed to control and generate signals for the DB25 interface for the RF amplifier | 27.95 or Free from makerspace | Link (https://www.amazon.ca/ELEGOO-Compatible-Arduino-Projects-Compliant/dp/B01H4ZLZLQ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) | No. Will use personal arduino for testing, and potentially makerspace arduino for project.
Cable Sleeve | Generally just to make the connections to the DB25 Connector neater. 10Feet Option 1/2"" | 13.99 | Link (https://www.amazon.ca/Alex-Tech-10ft-Protector-Sleeving/dp/B07FW3GTXB?sp_csd=d2lkZ2V0TmFtZT1zcF9hdGY) | No. More of a final item requirement. Mainly for aesthetics
Breakout Module for Arduino Mega | Wires connecting the DB25 adapter to the arduino. This breakout module allows us to securely connect each wire using screw locks. | 49.83 | Link (https://www.amazon.ca/Electronics-Salon-Terminal-Breakout-Arduino-MEGA-2560/dp/B07H9TJCWN) | No. More of a final item requirement. Mainly for durability and ensuring connections do not wiggle our of place and are securely connected.
Total | 109.09

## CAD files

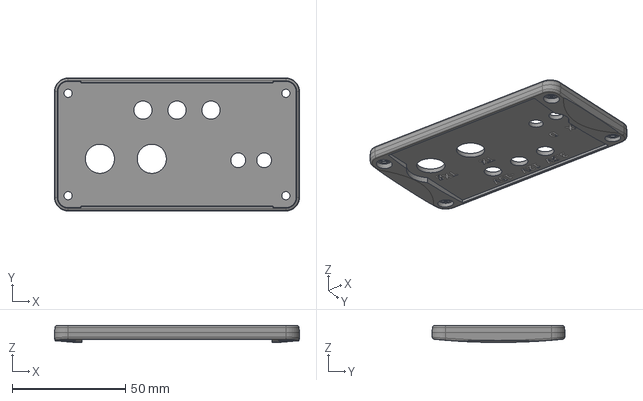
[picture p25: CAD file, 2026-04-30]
TEAM Files/03 - TR Switch/A4IM_TR-Switch_Rev003_Housing_Rev001_CAD_Front.step
108.0 x 58.6 x 7.50 mm

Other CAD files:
TEAM Files/03 - TR Switch/A4IM_TR-Switch_Rev003.step
TEAM Files/03 - TR Switch/A4IM_TR-Switch_Rev003_Housing_Rev001_Front_x100.dxf
TEAM Files/03 - TR Switch/A4IM_TR-Switch_Rev003_Housing_Rev001_CAD.step

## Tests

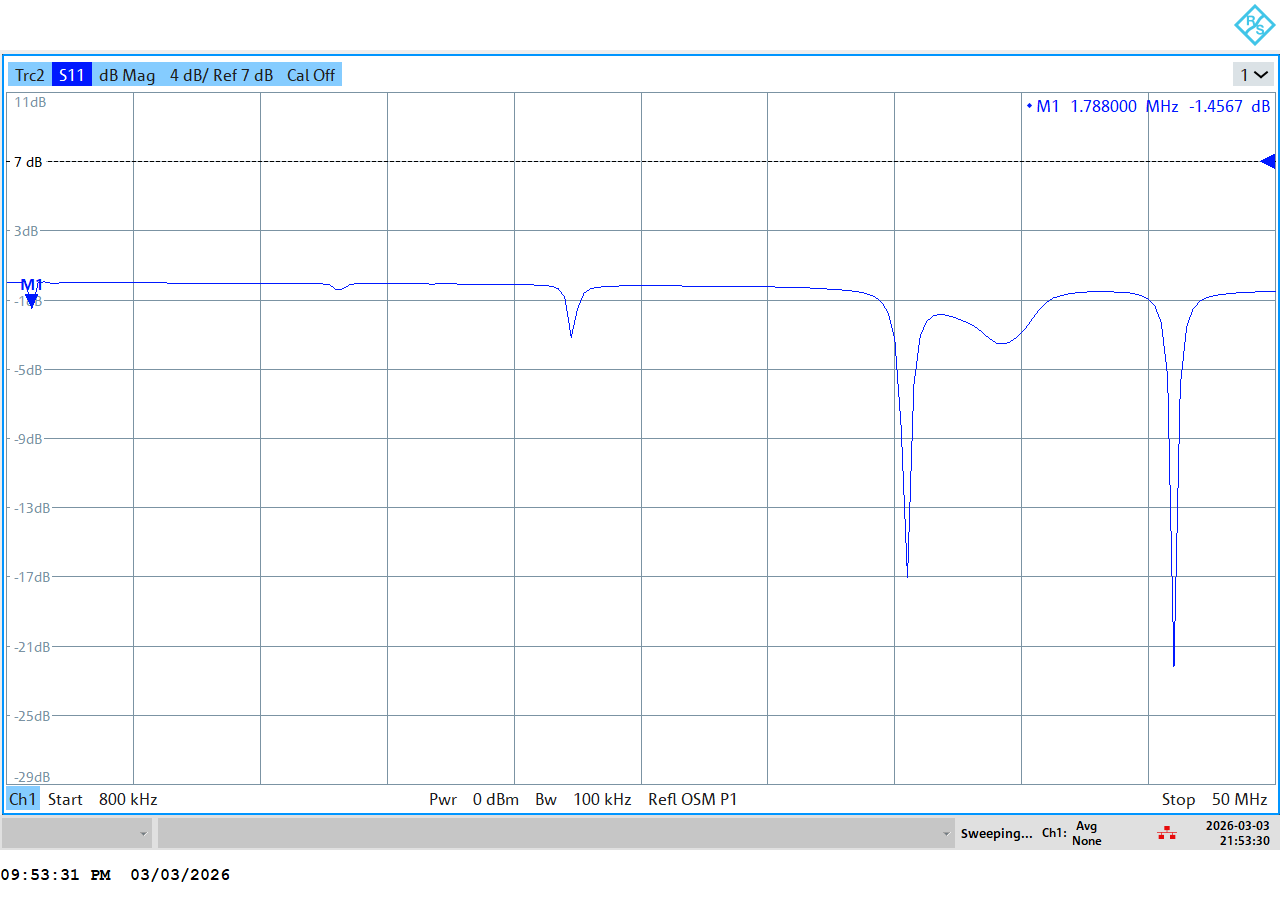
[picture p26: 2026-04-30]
TEAM Files/05 - Coil /VNA Screenshots for Capstone/S11 tune match 1.PNG

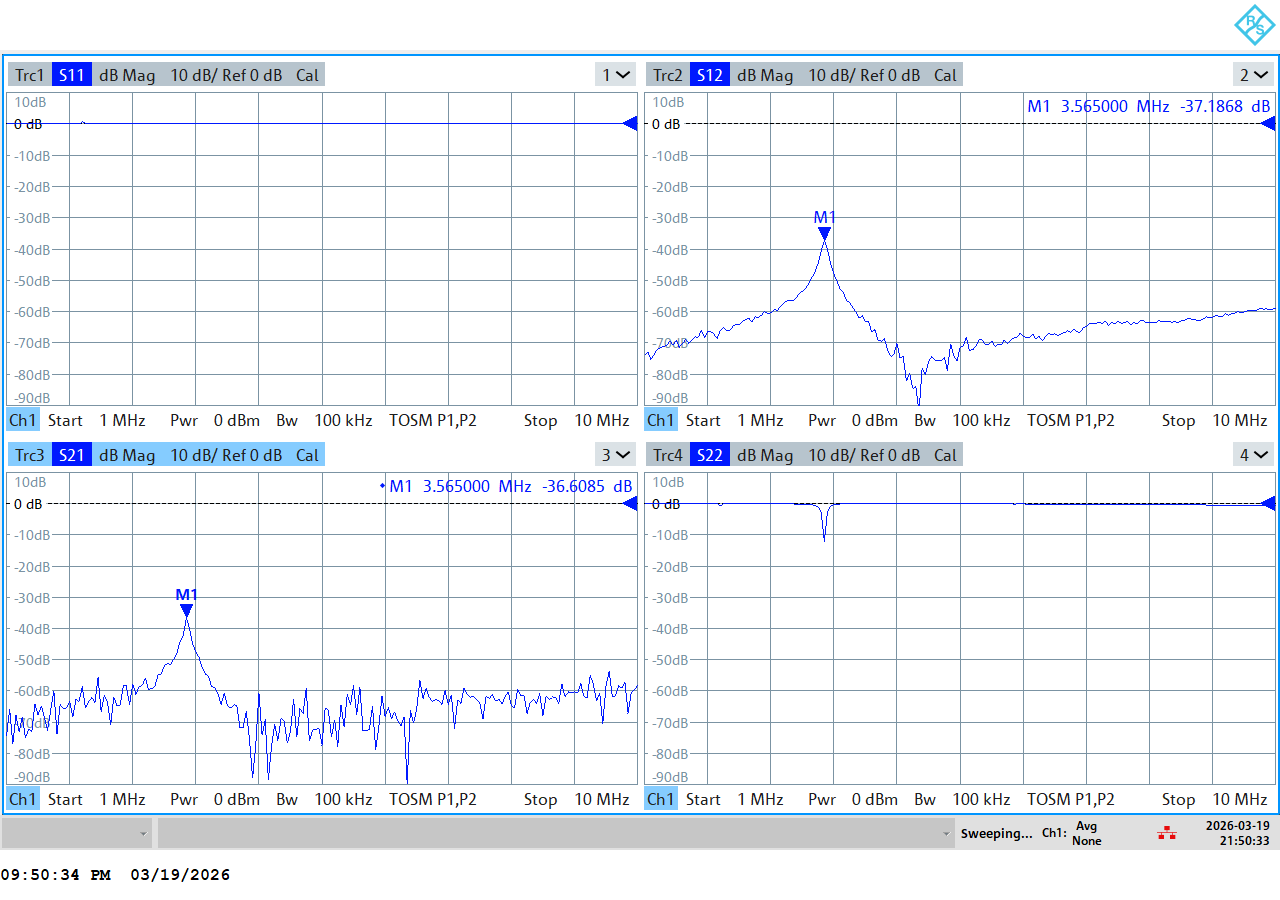
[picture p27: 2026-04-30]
TEAM Files/05 - Coil /VNA Screenshots for Capstone/march24_coil1_pcb_tuneNmatch_3dBQfactor.PNG

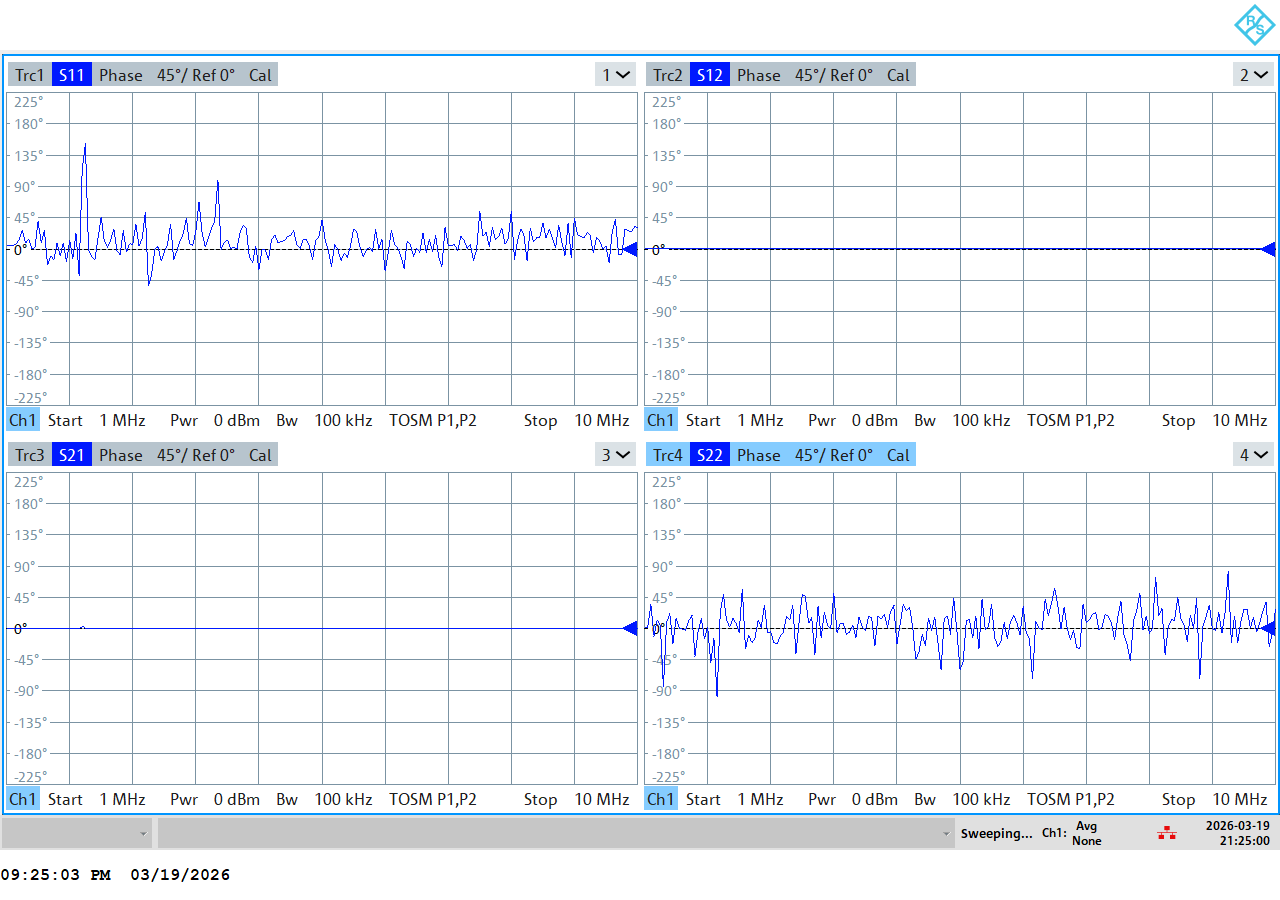
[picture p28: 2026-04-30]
TEAM Files/05 - Coil /VNA Screenshots for Capstone/ManualTOSMCalibration_matchPort2_phase.PNG

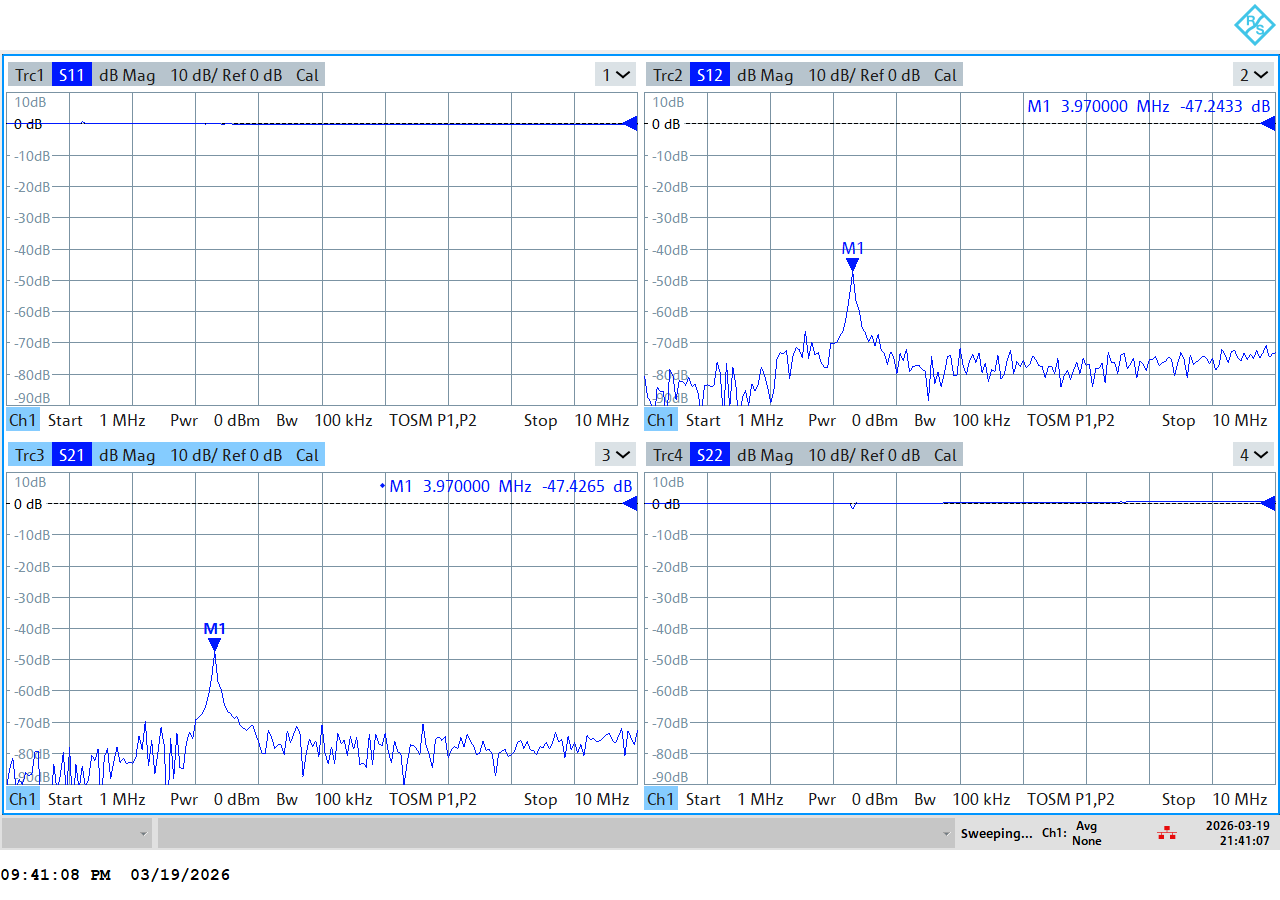
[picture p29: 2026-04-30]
TEAM Files/05 - Coil /VNA Screenshots for Capstone/march24_coil1_pcb_tuneNmatch_S11.PNG

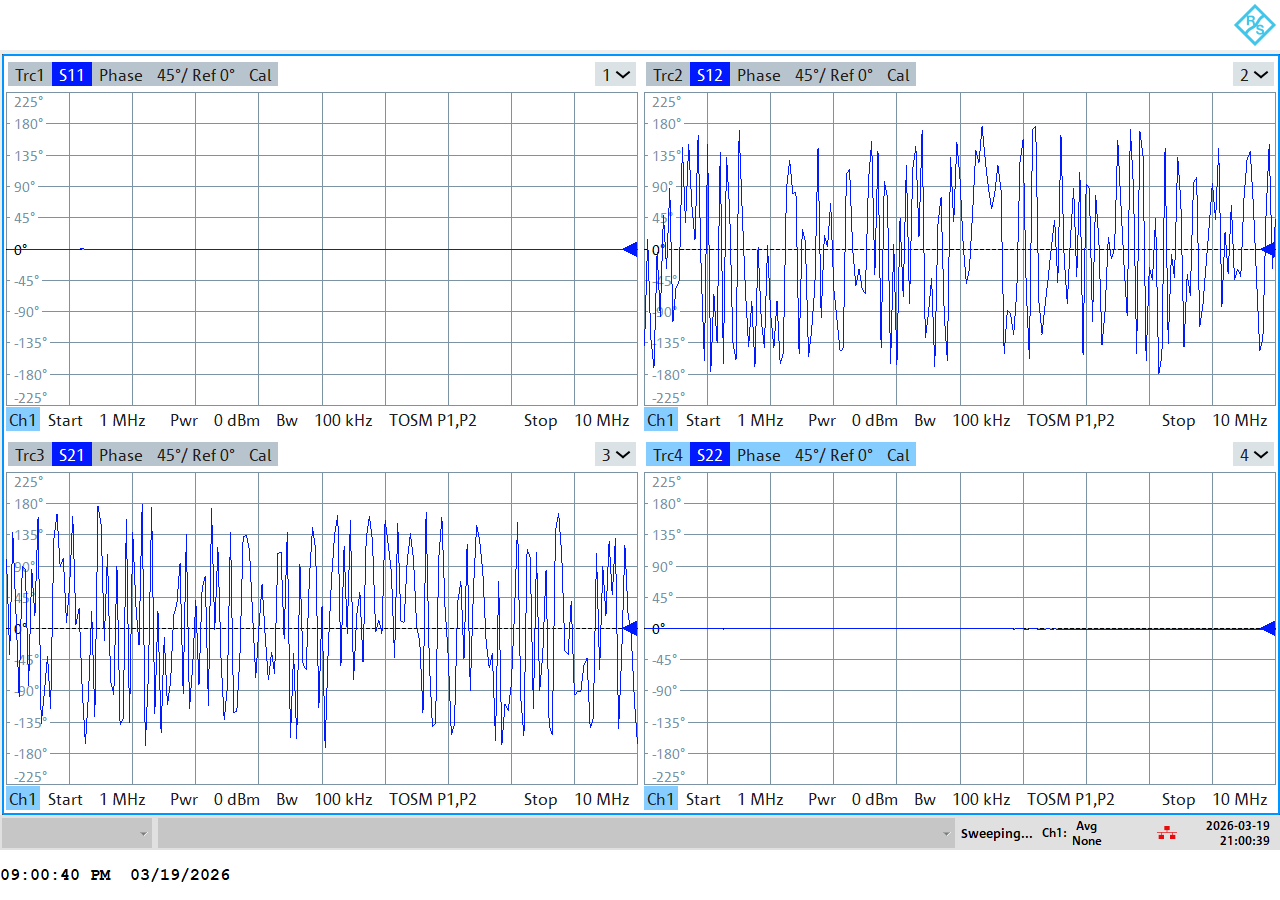
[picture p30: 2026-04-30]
TEAM Files/05 - Coil /VNA Screenshots for Capstone/ManualTOSMCalibration_through_mag.PNG

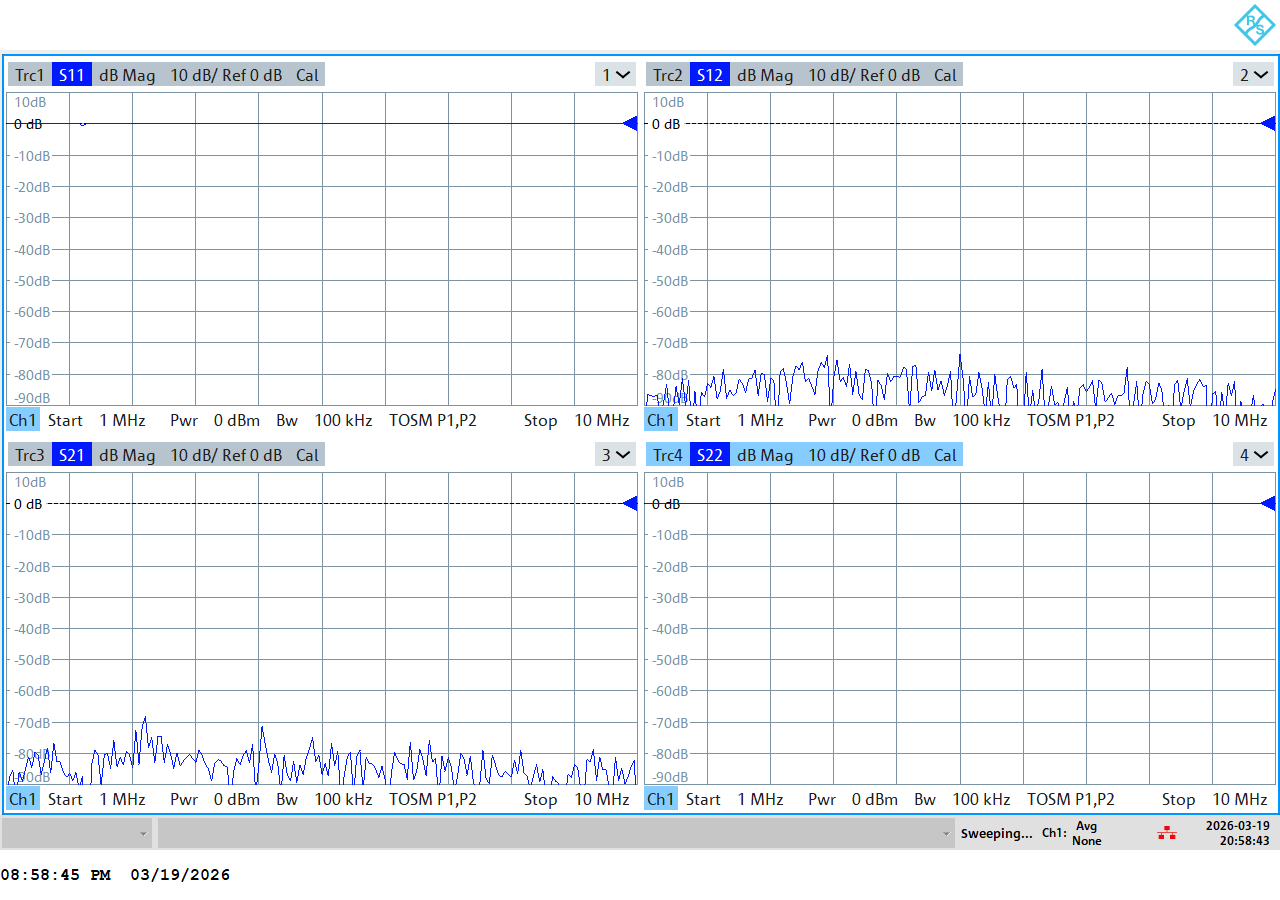
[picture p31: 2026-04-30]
TEAM Files/05 - Coil /VNA Screenshots for Capstone/ManualTOSMCalibration_short_phase.PNG

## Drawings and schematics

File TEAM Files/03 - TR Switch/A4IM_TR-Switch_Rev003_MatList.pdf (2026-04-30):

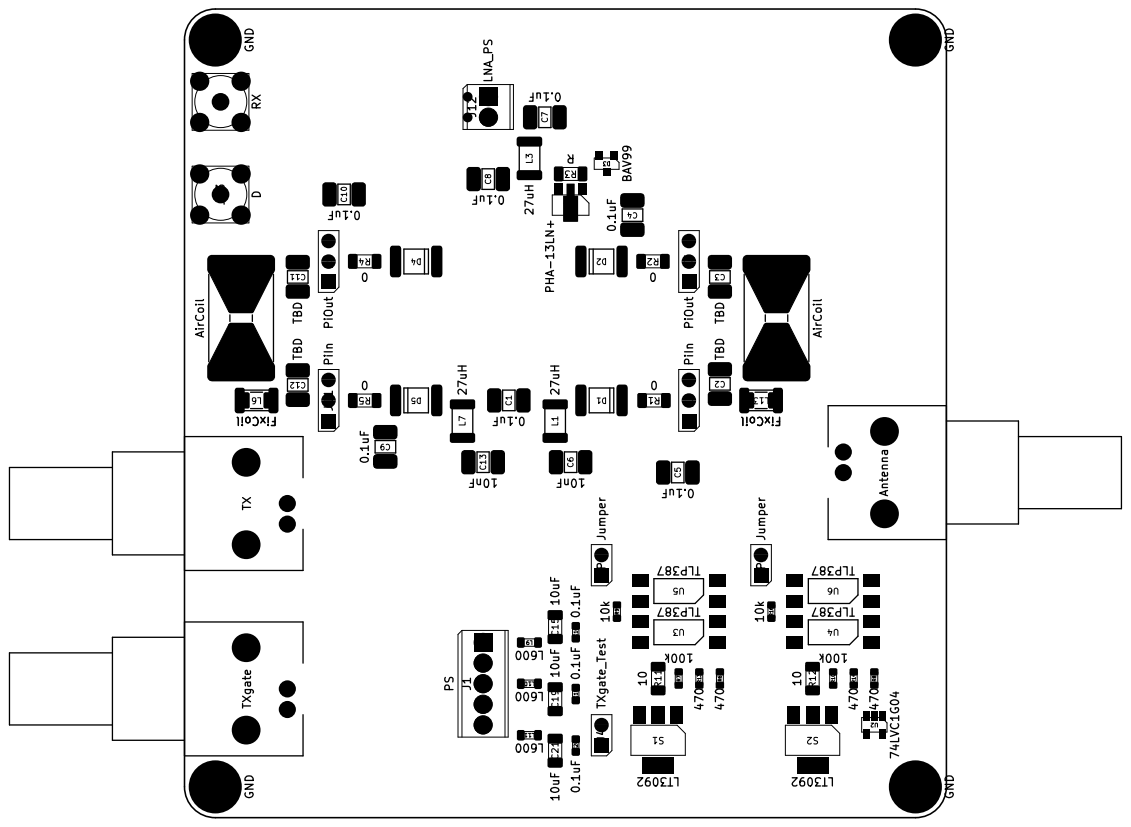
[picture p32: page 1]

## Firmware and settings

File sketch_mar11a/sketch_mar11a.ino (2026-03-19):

// ---------------- PIN MAP ----------------
#define DC_POWER 26
#define FWD_POWER 2
#define OVER_TEMP 3        // <-- NOW INPUT
#define OVER_DUTY 4        // <-- NOW INPUT
#define GAIN_CONTROL 5
#define REFL_POWER_LIMIT 6
#define VFWD 7
#define VREFL 8
#define FAULT 9
#define TRG_GT_SELECT 10
#define SHUTDOWN_STATUS 11
#define ADDRESS_SELECTED 12
#define ADDR3 13

#define ENABLE_STATUS 14
#define MISMATCH 15
#define PTT_IN 20
#define SYSLINK 17

#define AUX 18             // <-- INPUT
#define SHUTDOWN 19
#define GATE_IN 16
#define GND 21
#define PSU_ADJUST 22
#define ADDR0 23
#define ADDR1 24
#define ADDR2 25

// ---------------- INTERNAL STATE ----------------
int currentGain = 50;

// ---------------- GUI CONNECTION / HEARTBEAT ----------------
bool guiConnected = false;
unsigned long lastCmdTime = 0;

unsigned long lastHeartbeat = 0;
bool heartbeatState = false;
const int heartbeatOn = 2;   // 2ms ON
const int heartbeatOff = 2;  // 2ms OFF

// ---------------- PULSE ENGINE ----------------
bool pulseEnabled = false;
unsigned long pulseOnMs = 1;
unsigned long pulseOffMs = 4;
unsigned long lastPulseToggle = 0;
bool gateState = false;

// ---------------- SETUP ----------------
void setup() {
  Serial.begin(57600);
 Serial.begin(57600);

  // All input pins with internal pull-up enabled
  pinMode(DC_POWER, INPUT_PULLUP);
  pinMode(FWD_POWER, INPUT_PULLUP);
  pinMode(OVER_TEMP, INPUT_PULLUP);
  pinMode(OVER_DUTY, INPUT_PULLUP);
  pinMode(REFL_POWER_LIMIT, INPUT_PULLUP);
  pinMode(VFWD, INPUT_PULLUP);
  pinMode(VREFL, INPUT_PULLUP);
  pinMode(FAULT, INPUT_PULLUP);
  pinMode(TRG_GT_SELECT, INPUT_PULLUP);
  pinMode(SHUTDOWN_STATUS, INPUT_PULLUP);
  pinMode(ADDRESS_SELECTED, INPUT_PULLUP);
  pinMode(ENABLE_STATUS, INPUT_PULLUP);
  pinMode(MISMATCH, INPUT_PULLUP);
  pinMode(SYSLINK, INPUT_PULLUP);
  pinMode(AUX, INPUT_PULLUP);

  // Output pins remain as before
  pinMode(GAIN_CONTROL, OUTPUT);
  pinMode(ADDR3, OUTPUT);
  pinMode(PTT_IN, OUTPUT);
  pinMode(SHUTDOWN, OUTPUT);
  pinMode(GATE_IN, OUTPUT);
  pinMode(PSU_ADJUST, OUTPUT);
  pinMode(ADDR0, OUTPUT);
  pinMode(ADDR1, OUTPUT);
  pinMode(ADDR2, OUTPUT);

  pinMode(LED_BUILTIN, OUTPUT);

  // DEFAULT VALUES
  analogWrite(GAIN_CONTROL, currentGain);

  digitalWrite(ADDR3, LOW);
  digitalWrite(PTT_IN, LOW);
  digitalWrite(SHUTDOWN, HIGH);   // default HIGH
  digitalWrite(GATE_IN, LOW);     // default LOW
  digitalWrite(PSU_ADJUST, LOW);
  digitalWrite(ADDR0, LOW);
  digitalWrite(ADDR1, LOW);
  digitalWrite(ADDR2, LOW);
}

// ---------------- COMMAND HANDLER ----------------
void handleCommand(String cmd) {
  cmd.trim();

  guiConnected = true;
  lastCmdTime = millis();

  // Digital pin control: SET <pin> <0/1>
  if (cmd.startsWith("SET")) {
    int s1 = cmd.indexOf(' ');
    int s2 = cmd.indexOf(' ', s1 + 1);

    int pin = cmd.substring(s1 + 1, s2).toInt();
    int value = cmd.substring(s2 + 1).toInt();

    digitalWrite(pin, value);
  }

  // Gain control
  if (cmd.startsWith("GAIN")) {
    int spaceIndex = cmd.indexOf(' ');
    int gainValue = cmd.substring(spaceIndex + 1).toInt();

    currentGain = constrain(gainValue, 0, 255);
    analogWrite(GAIN_CONTROL, currentGain);
  }

  // Flash test
  if (cmd == "F") digitalWrite(LED_BUILTIN, HIGH);
  if (cmd == "S") digitalWrite(LED_BUILTIN, LOW);

  // ---------------- PULSE COMMAND ----------------
  if (cmd.startsWith("PULSE")) {

    if (cmd == "PULSE STOP") {
      pulseEnabled = false;
      gateState = false;
      digitalWrite(GATE_IN, LOW);
      return;
    }

    int s1 = cmd.indexOf(' ');
    int s2 = cmd.indexOf(' ', s1 + 1);

    pulseOnMs = cmd.substring(s1 + 1, s2).toInt();
    pulseOffMs = cmd.substring(s2 + 1).toInt();

    pulseEnabled = true;
    gateState = false;
    digitalWrite(GATE_IN, LOW);
    lastPulseToggle = millis();
  }
}

// ---------------- MAIN LOOP ----------------
void loop() {

  if (Serial.available()) {
    String cmd = Serial.readStringUntil('\n');
    handleCommand(cmd);
  }

  // Auto-disconnect
  if (guiConnected && millis() - lastCmdTime > 3000) {
    guiConnected = false;
    pulseEnabled = false;
    gateState = false;
    digitalWrite(GATE_IN, LOW);
  }

  // Heartbeat
  if (!guiConnected) {
    unsigned long now = millis();

    if (!heartbeatState && now - lastHeartbeat >= heartbeatOff) {
      heartbeatState = true;
      digitalWrite(LED_BUILTIN, HIGH);
      lastHeartbeat = now;
    }
    else if (heartbeatState && now - lastHeartbeat >= heartbeatOn) {
      heartbeatState = false;
      digitalWrite(LED_BUILTIN, LOW);
      lastHeartbeat = now;
    }
  }

  // Pulse engine
  if (pulseEnabled) {
    unsigned long now = millis();

    if (!gateState && now - lastPulseToggle >= pulseOffMs) {
      gateState = true;
      digitalWrite(GATE_IN, HIGH);
      lastPulseToggle = now;
    }
    else if (gateState && now - lastPulseToggle >= pulseOnMs) {
      gateState = false;
      digitalWrite(GATE_IN, LOW);
      lastPulseToggle = now;
    }
  }

  // ---------------- SEND INPUT PACKET ----------------
Serial.print("IN:");
Serial.print(digitalRead(DC_POWER)); Serial.print(",");         // 1
Serial.print(digitalRead(FWD_POWER)); Serial.print(",");        // 2
Serial.print(digitalRead(OVER_TEMP)); Serial.print(",");        // 3
Serial.print(digitalRead(OVER_DUTY)); Serial.print(",");        // 4
Serial.print(digitalRead(REFL_POWER_LIMIT)); Serial.print(","); // 6
Serial.print(digitalRead(VFWD)); Serial.print(",");             // 7
Serial.print(digitalRead(VREFL)); Serial.print(",");            // 8
Serial.print(digitalRead(FAULT)); Serial.print(",");            // 9
Serial.print(digitalRead(TRG_GT_SELECT)); Serial.print(",");    // 10
Serial.print(digitalRead(SHUTDOWN_STATUS)); Serial.print(",");  // 11
Serial.print(digitalRead(ADDRESS_SELECTED)); Serial.print(","); // 12
Serial.print(digitalRead(ENABLE_STATUS)); Serial.print(",");    // 14
Serial.print(digitalRead(MISMATCH)); Serial.print(",");         // 15
Serial.print(digitalRead(SYSLINK)); Serial.print(",");          // 17
Serial.print(digitalRead(AUX));                                  // 18
Serial.println();

  // ---------------- SEND OUTPUT PACKET ----------------
  Serial.print("OUT:");


  Serial.print(currentGain); Serial.print(","); //5

  Serial.print(digitalRead(ADDR3)); Serial.print(","); //13
  Serial.print(digitalRead(GATE_IN)); Serial.print(","); //22
  Serial.print(digitalRead(SHUTDOWN)); Serial.print(","); //19
  Serial.print(digitalRead(PTT_IN)); Serial.print(","); //18
  Serial.print(digitalRead(PSU_ADJUST)); Serial.print(","); //23
  Serial.print(digitalRead(ADDR0)); Serial.print(","); //24
  Serial.print(digitalRead(ADDR1)); Serial.print(","); //25
  Serial.print(digitalRead(ADDR2));
  Serial.println();

  delay(100);
}
